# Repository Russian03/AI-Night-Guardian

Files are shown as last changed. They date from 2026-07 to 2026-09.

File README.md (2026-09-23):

# AI Night Guardian

> Acoustic detection of night-time incidents in care homes, running locally
> on-device and **without recording or storing any audio**.

Submitted to **HackEstiu 2026** (Universitat Politècnica de Catalunya).

- **Team:** Jan Díaz Carreras-Candi · Guillem Guilera Aulet · Joan Montobbio Palmer
- **Affiliation:** ETSETB — Universitat Politècnica de Catalunya (UPC), Barcelona
- **Hardware:** Arduino UNO Q + Modulino (temperature / light) + USB-C lavalier microphone + 3D printed enclosure
- **License:** MIT — see [`LICENSE`](LICENSE)
- **Arduino Project Hub (public):** see [`Arduino Project Hub`](https://projecthub.arduino.cc/guillemguilera/ai-night-guardian-5e5ab9)
- **Edge Impulse™ project (public):** see [`Edge Impulse`](https://studio.edgeimpulse.com/public/1106722/live)
- **Demo video:** see [`Video`](https://youtu.be/zw-_enrB-u0)

---

## 1. The problem

In care homes, night staff work by rounds: they walk into each room to
check that the resident is all right. Depending on the facility, a given
room gets a visit roughly once an hour.

That means there is up to an hour in which nobody knows what is happening
inside a room. If someone falls, if someone is in distress, it gets noticed
on the next round — not when it happens.

The obvious technical fix is a camera or an always-on microphone. But these
are people's bedrooms, and continuous recording in a resident's room is not
something anyone should accept. Any system that goes in there has to work
without keeping the audio.

## 2. The solution

**AI Night Guardian** is a device built on an Arduino UNO Q that runs a
neural network **locally** to classify sounds inside a room. It doesn't
replace the rounds — it covers the time between them.

The model distinguishes five kinds of sound, chosen so that each one maps
to a different action:

| Class | What it covers | Device action |
|---|---|---|
| `impacte` | Impacts, falls, doors | Alert |
| `veu_angoixa` | Screaming, crying, distress | Alert |
| `tos` | Coughing fits | Alert |
| `normal` | Speech, snoring, rain, traffic, alarms | Nothing |
| `silenci` | A quiet room | Nothing |

When it detects an incident, the device records the time and the type and
publishes a notification to the staff's mobile app, so carers can
prioritise the rooms that actually need attention.

**Additional:**

In the app you can find the temperature and light information of each room via the two Modulino sensors.

Because it is a **low-cost system with local processing**, it can be
deployed in care homes, assisted-living facilities and even in the homes of
older people living alone.

## License

MIT — see [`LICENSE`](LICENSE).

The source datasets (AudioSet, FSD50K, COUGHVID, ESC-50) keep their own
licenses; check them before redistributing `dataset_final_16khz/`.

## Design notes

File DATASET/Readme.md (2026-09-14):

Datasets:
* AudioSet: millions of 10s clips extracted from YouTube; it does not have video files, only a .csv file with the videos' IDs and the start and end time of each clip, as well as the assigned classes.
  - URL: https://research.google.com/audioset/download.html
* Coughvid: more than 20000 recordings of coughing sounds.
  - URL: https://zenodo.org/records/4048312
* ESC 50: 2000 5s audios, with special focus on environmental sounds.
  - URL: https://github.com/karolpiczak/esc-50
* FSD50K: more than 50000 audio clips from Freesound with 200 different sound-classes. The audios' length varies between 0.3s and 30s.
  - URL: https://zenodo.org/records/4060432

Scripts:
* audioset_extractor.py: filters the dataset and donwloads only the selected videos.
* coughvid_extractor.py: filters the locally downloaded coughvid dataset.
* esc50_extractor.py: filters the locally downloaded esc50 dataset.
* fsd50k_extractor.py: filters the locally downloaded coughvid dataset.
* UNIFICADOR.py: converts all selected videos by the previous scripts to 16kHz mono format.

Requisites:
* python3
  - os
  - pandas
  - sutil
  - subprocess
* FFmpeg

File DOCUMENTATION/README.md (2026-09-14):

# AI Night Guardian — Reproduction Guide

Complete guide to build the system from scratch: 3D-printed parts, Arduino UNO Q firmware and mobile app.

No prior knowledge of Arduino, Flutter or 3D printing is assumed. Follow the blocks in order: block 3 (firmware) only depends on block 2 if you want the enclosure assembled, but block 4 (app) requires the firmware to be running first.

---

## 0. Repository layout

```
APP/                        Mobile application (Flutter)
ARDUINO/
  ├── ai_night_guardian_firmware.tar.gz        Full Arduino App Lab application
  └── 3D_DESIGNS/                              Enclosure models (.obj / .stl)
```

Inside the `.tar.gz`, the App Lab application has this shape:

```
ai_night_guardian_firmware/
  ├── app.yaml              App Lab application definition
  ├── python/
  │    ├── main.py          Entry point: launches the three processes
  │    └── device_identity.py   Identity + QR generator
  ├── ai_night_guardian/
  │    ├── bleperipheral.py     BLE provisioning
  │    ├── mqtt_publisher.py    Heartbeat, sensors and configuration
  │    ├── audio_publisher.py   Audio inference and event publishing
  │    └── *.eim                Edge Impulse model
  ├── sketch/sketch.ino     Microcontroller code (Modulino sensors)
  └── requirements.txt      Python dependencies
```

---

## 1. What you need

**Hardware**

| Item | Notes |
|---|---|
| Arduino UNO Q (4 GB) + USB-C power	| The MPU side is what runs Linux and the model | 
| USB-C microphone	| Audio input for the classifier | 
| USB-C hub	| The board has a single USB-C port, so the hub is what lets you power it and plug the microphone in at the same time | 
| Modulino temperature and light sensors	| Daisy-chained over Qwiic/I2C | 
| USB-C cable to PC	| For the initial setup | 
| Android phone	| For the app | 

**Software on the PC**

| Program | Purpose |
|---|---|
| [Arduino App Lab](https://www.arduino.cc/en/software) | Load and run the firmware |
| [Ultimaker Cura](https://ultimaker.com/software/ultimaker-cura/) | Prepare the 3D parts |
| [Flutter SDK](https://docs.flutter.dev/get-started/install) | Build the app |
| [Git](https://git-scm.com/) | **Required**: the Flutter SDK uses it internally, and without it no `flutter` or `dart` command works |
| Android Studio (or just the command-line tools + SDK) | Build for Android |

---

## 2. 3D-printed parts

The files live in `ARDUINO/3D_DESIGNS/`. An `.stl` or `.obj` is geometry only: it describes the shape but knows nothing about your printer. You need a **slicer** to turn that shape into the movement instructions the machine understands (a `.gcode` file).

### 2.1 Preparing the file in Cura

1. Install Ultimaker Cura and open it.
2. On first launch it asks you to **add a printer**. Pick your exact model from the list. If it isn't there, use *Add a non-networked printer → Custom* and enter the build volume and nozzle diameter (usually 0.4 mm). This step is what makes the resulting `.gcode` valid for your machine.
3. `File → Open File(s)` and select the `.stl` (or the `.obj`; Cura accepts both, `.stl` being the standard for printing).
4. The part appears on the virtual bed. Check:
   - **Orientation**: use *Rotate* to lay the largest flat face on the bed. It reduces supports and improves adhesion.
   - **Size**: with *Scale*, verify the dimensions are what you expect. If the model imports 1000× too small, that's a unit problem in the `.obj` — use the `.stl` instead.

### 2.2 Recommended settings

| Setting | Value | Reason |
|---|---|---|
| Material | PLA | Enough for indoor use, easiest to print |
| Layer height | 0.2 mm | Balance between quality and time |
| Infill | 15–20 % | The enclosure carries no load |
| Walls | 2–3 | Sufficient rigidity |
| Supports | Only for overhangs >45° | Cura highlights them in red once *Support* is enabled |
| Bed adhesion | *Brim* | Stops corners from lifting |

### 2.3 Printing

1. Click **Slice** (bottom right). Cura computes the toolpath and shows estimated time and material.
2. Check the *Preview* view to make sure no layers are printing into thin air.
3. **Save to Disk** or **Save to Removable Drive**: writes the `.gcode` to the printer's SD card or USB stick.
4. Insert the media into the printer, pick the file on its screen and start the print.

Print every part in the directory before assembling. The microphone must line up with the grille in the enclosure: do not cover it with material, inference depends directly on the acoustic signal.

---

## 3. Arduino UNO Q firmware

### 3.1 First contact with the board

1. Install **Arduino App Lab** on the PC and open it.
2. Connect the UNO Q to the PC with the USB-C cable and wait for App Lab to detect it.
3. Enter the **board's WiFi credentials** when prompted. This is the network the device publishes from over MQTT; it must be the same network (or one with Internet access) that the phone uses.
4. If App Lab offers a board system update, install it and reboot. Do this now, not after loading the application.

### 3.2 Loading the application

App Lab imports packaged applications. Extract the tar first if your version only accepts a folder or a `.zip`:

```bash
tar -xzf ai_night_guardian_firmware.tar.gz
```

In the interface:

1. Go to **My Apps**.
2. Click **Create New App → Import App**.
3. Select the **whole** package (the `.tar.gz` or the complete `ai_night_guardian_firmware` folder, not individual files). The app bundles the Python code, the microcontroller sketch and `app.yaml`; if you import loose pieces, App Lab won't recognise it as an application.
4. The application shows up as a card under **My Apps**.

Terminal equivalent (from inside the UNO Q):

```bash
arduino-app-cli app import ai_night_guardian_firmware.tar.gz
```

### 3.3 Placing the AI model

The `.eim` file is the compiled model and may not be in the repository because of its size. If it's missing:

1. In Edge Impulse Studio, open the project → **Deployment**.
2. Choose **Linux (AARCH64)** and hit *Build*. You get an `.eim` file.
3. Copy it into the application's `ai_night_guardian/` folder over SCP:

   ```bash
   scp model.eim arduino@<UNO_Q_IP>:/home/arduino/ArduinoApps/ai_night_guardian_firmware/ai_night_guardian/
   ```

4. Make it executable (it's a binary, not a data file):

   ```bash
   ssh arduino@<UNO_Q_IP> "chmod +x /home/arduino/ArduinoApps/ai_night_guardian_firmware/ai_night_guardian/*.eim"
   ```

5. Open `audio_publisher.py` and check that the `EIM_PATH` constant holds **exactly** your file name. If it doesn't match, the script falls into its retry loop and never classifies anything.

### 3.4 Setting the microphone

`audio_publisher.py` has `AUDIO_DEVICE_ID = 8`. That number identifies the microphone on *that* board and changes with the hardware and the order things were plugged in. To find yours, in the UNO Q terminal:

```bash
python3 -m sounddevice
```

Find your microphone in the list (or the `default` entry) and put its index in `AUDIO_DEVICE_ID`.

### 3.5 Running it

1. With the application open in App Lab, press **Run**. The first run installs the dependencies from `requirements.txt` and takes several minutes.
2. Open the App Lab **Console**. You should see, in this order:

   ```
   [AI Night Guardian] device_id: AING-XXXXXX
   BLE peripheral launched
   MQTT publisher launched
   Audio publisher launched (nice 10)
   [MQTT audio] Conectado al broker, codigo: Success
   [AI Night Guardian] Modelo cargado. Clases: [...]
   [ESCUCHA] Micrófono e inferencia ACTIVOS
   ```

   If it keeps repeating *Audio no disponible todavía*, go back to 3.3 and 3.4.
3. This first run creates `device_identity.json` and `provisioning_qr.png` inside the application folder. **Download that PNG** — it's the QR the app scans to pair:

   ```bash
   scp arduino@<UNO_Q_IP>:/home/arduino/ArduinoApps/ai_night_guardian_firmware/python/provisioning_qr.png .
   ```

   Print it and stick it on the enclosure. Never publish it anywhere: it contains the device's pairing key.

### 3.6 Run at startup

A monitoring device has to come back on its own after a power cut, without anyone opening App Lab.

1. In the top right corner, next to the **Run** button, click the **arrow (▼)** to open the menu.
2. Turn on the **Run at startup** toggle.
3. A **DEFAULT** badge appears next to the application name, confirming it will start on boot.

Terminal equivalent:

```bash
arduino-app-cli properties set default user:ai_night_guardian_firmware
```

Test it for real: unplug power, plug it back in, wait a minute and check that the device reappears in the app.

---

## 4. Mobile application

The code is in `APP/`. It's built with Flutter and validated on Android.

### 4.1 Setting up the environment

1. Install **Git** and confirm it responds from a fresh terminal:

   ```bash
   git --version
   ```

   Without it, Flutter commands fail with errors about `update_engine_version`.
2. Install the **Flutter SDK** and add it to your PATH.
3. Run the diagnostic and fix everything it flags in red:

   ```bash
   flutter doctor
   ```

   For Android you need the SDK installed and the licences accepted (`flutter doctor --android-licenses`).

### 4.2 Build and install

```bash
cd APP
flutter pub get
```

With the phone connected over USB and **USB debugging** enabled in developer options:

```bash
flutter devices     # confirm your phone shows up
flutter run
```

To produce an APK you can install without a cable:

```bash
flutter build apk --release
```

The file lands in `build/app/outputs/flutter-apk/app-release.apk`. Copy it to the phone and install it, accepting the unknown-sources warning.

### 4.3 Phone permissions

Grant these when the app asks, or under *Settings → Apps → AI Night Guardian → Permissions*:

- **Camera**: scanning the device QR.
- **Bluetooth / Nearby devices**: BLE provisioning.
- **Location**: Android requires it for BLE scanning even though position is never used.
- **Notifications**: without this you won't see alerts.

The phone and the UNO Q must be on the **same WiFi network**.

---

## 5. Pairing device and app

With the firmware running (block 3) and the app installed (block 4):

1. Open the app → **Add device**.
2. **Scan the QR** stuck on the enclosure. The app reads the `device_id` and the pairing key.
3. The app looks for the device over **Bluetooth**. Keep the phone within a metre.
4. Enter the facility's **WiFi SSID and password** and confirm the **room name**.
5. Wait for confirmation. The process has a countdown of up to 90 seconds: it needs both the BLE reply **and** the first MQTT heartbeat. Don't leave the screen early.
6. The device appears in the list with a green indicator.

### Final check

1. Open the device detail view and confirm temperature and light are updating (they should refresh every few seconds).
2. Make sure the **acoustic listening** toggle is on. If it's off, the microphone is never even opened and nothing will be detected.
3. Trigger an event: clap loudly near the microphone. The UNO Q console shows the classification and, if it clears the threshold, `[EVENTO enviado]`; the notification should reach the phone within seconds.

Coughing won't fire on a single burst: the system requires several distinct coughs within a time window to tell a real coughing fit from throat-clearing. To test it, cough repeatedly for about half a minute.

---

## 6. Troubleshooting

| Symptom | Most likely cause | Fix |
|---|---|---|
| `Audio no disponible todavia` looping | `.eim` missing, not executable, or wrong `AUDIO_DEVICE_ID` | Review 3.3 and 3.4 |
| Many alerts from an empty room | Silence threshold (`SILENCE_RMS`) below the real background noise | Set `DEBUG_RMS = True` for a minute, read the idle values and raise the threshold |
| Temperature and light arrive as `null` | Inference is hogging the CPU | Confirm `main.py` launches the audio process with `nice -n 10` |
| Device shows as offline | The UNO Q lost WiFi or the process stopped | Check the App Lab console; confirm **Run at startup** is enabled |
| App can't find the device over BLE | Bluetooth or location permission off; provisioning window closed | Enable both and reboot the device to reopen the BLE window |
| No `flutter` or `dart` command works | Git isn't on the PATH | Install Git and open a new terminal |
| Icon or text doesn't update after rebuilding | Android cache | Uninstall the app from the phone, reboot it, then reinstall |

---

## 7. Privacy note

Audio is never stored or transmitted: it's processed in memory in one-second windows and discarded immediately after inference. The only thing leaving the device is text metadata (room, time, incident type). Any firmware change must preserve this property — it's the basis for the system qualifying legally as an automated emergency sensor rather than a listening microphone.

The default MQTT broker is public (`broker.hivemq.com`), which is fine for a demo. Before any real deployment it must be replaced by your own broker with TLS and per-device credentials.

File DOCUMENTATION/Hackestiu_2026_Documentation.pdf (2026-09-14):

## AI Night Guardian

Acoustic detection of night-time incidents in care homes, with on-device inference and no audio retention

Jan Díaz Carreras-Candi | Guillem Guilera Aulet | Joan Montobbio Palmer

FIB — Universitat Politècnica de Catalunya
| HackEstiu 2026

Abstract

In care homes, night staff check each room on rounds roughly once an hour, which leaves up to an hour in which nobody knows what is happening inside a room. AI Night Guardian is a low-cost device that listens to a room and alerts staff the moment it detects an incident, running a neural network locally on an Arduino UNO Q and without ever storing or transmitting audio. This document describes the system, the dataset pipeline, the model, the on-device decision logic and the mobile application, along with the measured results and the known limitations.

### Contents

1 Problem | 3
2 System overview | 3
3 Hardware | 4
4 Repository layout | 5
5 Dataset | 6
6 Model | 7
7 On-device runtime | 10

8 Mobile application | 12
9 Reproducing the system | 13
10 Limitations | 14
11 Future work | 15
Resources | 15

### 1 Problem

In care homes, night staff work by rounds: they walk into each room to check that the resident is all right. Depending on the facility, a given room gets a visit roughly once an hour.
That means there is up to an hour in which nobody knows what is happening inside a room. If someone falls, if someone is in distress, it is noticed on the next round — not when it happens. The obvious technical fix is a camera or an always-on microphone. But these are people’s bedrooms, and continuous recording in a resident’s room is not acceptable, both as a matter of dignity and under GDPR. Any system deployed there has to work without keeping the audio.

Goal. A device that detects incidents at the moment they occur, costs little enough to be deployed in every room, and processes everything locally so that no audio ever leaves the room.

### 2 System overview

The device classifies the sound of the room into five categories, three of which raise an alert. When one fires, it publishes a short JSON message over MQTT and the staff’s mobile app raises a notification.

Class | Covers | Action
impacte | Impacts, falls, doors | Alert
veu_angoixa | Screaming, crying, distress | Alert
tos | Coughing fits | Alert
normal | Speech, snoring, rain, traffic, alarms None
silenci | A quiet room | None

Table 1: Classes and the action each one triggers on the device. The class names are the labels of the deployed impulse; the preprocessing scripts use the English equivalents (impact, distressed_voice, cough, normal).

Two non-acoustic alerts complete the system: temperature outside a configurable range, which matters during heatwaves, and changes in ambient light, which can flag a resident getting up in the middle of the night.

### 2.1 Architecture

ROOM
USB-C microphone --> Arduino UNO Q |
|-- MCU (Zephyr) sketch.ino
| Modulino Thermo + Light
| exposes read_sensors() over RouterBridge
‘-- Linux (Cortex-A) python/main.py audio_publisher.py mic -> .eim model -> events mqtt_publisher.py sensors + heartbeat + config ble_peripheral.py WiFi provisioning
| | | MQTT / TCP 1883

| residencia/<device_id>/{heartbeat,eventos,config}
| v
Mobile app (Flutter)
QR + BLE onboarding, dashboard, notifications

The split matters: the microcontroller only reads the two I²C sensors and answers requests over RouterBridge, while everything acoustic happens on the Linux side, where the Edge Impulse™ runtime and the MQTT client live. Audio never reaches the MCU.

Incident flow. Microphone → 1 s window in RAM → Mel-filterbank energies → audio window discarded → inference → if the energy gate, the confidence threshold, the burst rule and the refractory period all pass, a JSON text message is published over MQTT.

### 2.2 Privacy by design

This is the core constraint of the project and the reason it is deployable in a care home.
- No personal or biometric data is processed or stored.
- The acoustic signal is captured straight into memory.
- Once inference has run, the audio window is immediately and irreversibly discarded, having never been written anywhere.
- No audio is transmitted outside the room.
- The only thing that leaves the device is text metadata. The app’s local incident history stores the same metadata and nothing else.

{"type": "event", "device_id": "AING-9D67B1",
"ts": "2026-09-12T02:40:11+0200",
"payload": {"room": "Room 14", "event_type": "impacte",
"confidence": 0.85}}

Legally, the system behaves as an automated emergency sensor rather than a listening microphone. The app additionally exposes a per-room listening switch; turning it off does not merely discard results, it shuts down the model process and releases the audio device (Section 7.2).

### 3 Hardware

Component | Role
Arduino UNO Q (4 GB) | Main board; Linux (Cortex-A) plus a Zephyr MCU
T’nB Influence Lapel Mic USB-C Audio capture, 16 kHz mono
USB-C hub | Connects microphone and power to the board
Modulino Thermo | Room temperature and humidity
Modulino Light | Ambient light level
3D printed enclosure | Four parts; STL and OBJ in the repository

Table 2: Bill of materials.

The two Modulinos are daisy-chained on the board’s Qwiic I²C connector and read from the MCU through the Arduino_Modulino library; no extra wiring is needed beyond the chain. The microphone is a plain USB audio device: it is enumerated by Linux, not by the MCU, and the inference process opens it by index (AUDIO_DEVICE_ID).

Enclosure. Four printed parts, in ARDUINO/3D_DESIGNS/ as both STL and OBJ: case_front, case_back, microphone_support and modulinos_support. The two supports hold the microphone and the sensor chain in place so that the acoustic port and the light sensor are not obstructed by the cabling.

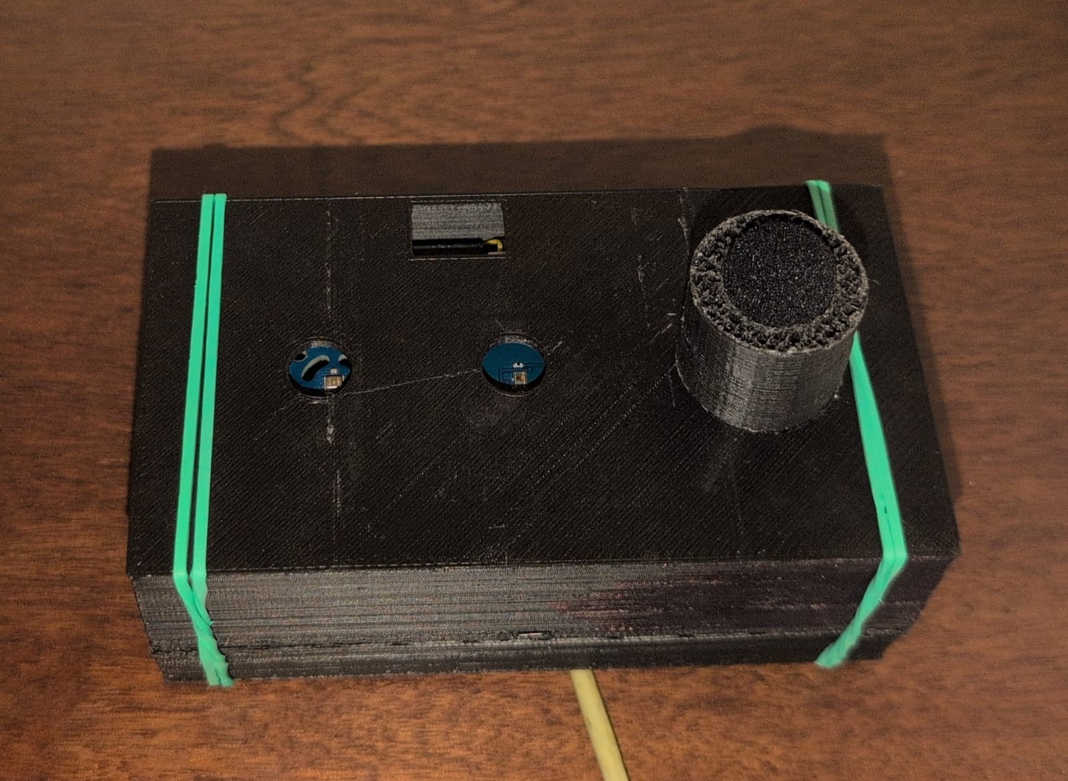
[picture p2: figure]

Figure 1: Device assembled.

### 4 Repository layout

Everything needed to rebuild the system is in the repository, including the audio collection and the deployed model binary.

AI-Night-Guardian/
|-- APP/ Flutter application (Android / iOS / desktop)
| |-- lib/data/ MQTT service, notifications, event log, storage
| |-- lib/presentation/ Screens: splash, home, devices, detail, QR,
| | BLE scan, WiFi provisioning, dashboard, settings
| ‘-- assets/translations/ ca.json, es.json, en.json
|-- ARDUINO/
| |-- 3D_DESIGNS/ Enclosure: 4 parts, STL + OBJ
| ‘-- ai_night_guardian_firmware.tar.gz
| sketch/sketch.ino MCU: Modulino + RouterBridge
| python/main.py Launches the three Linux processes | ai_night_guardian/
% audio_publisher.py Inference loop and decision logic % mqtt_publisher.py Sensor thread, heartbeat, config
% ble_peripheral.py GATT WiFi provisioning
% device_identity.py device_id, provisioning key, QR
% event_simulator.py Publishes fake incidents for demos
% *.eim Deployed Edge Impulse model (14 MB)
|-- DATA PREPROCESSING/ Dataset cleaning and preparation (6 scripts) | ‘-- recordings/ 501 two-second clips of the target room
|-- DATASET/
| |-- creation/Scripts/ Extractors for the four source datasets | ‘-- final_dataset_16khz/ 30,487 WAV clips, 16 kHz mono

|-- DOCUMENTATION/ This document and the design notes
‘-- LICENSE MIT

(The lines marked with % above are the contents of the firmware archive, which is shipped compressed.)

### 5 Dataset

The training set is built from public audio: 30 487 clips normalised to 16 kHz mono, in DATASET/final_dataset_16khz/.

Source | Clips | Origin
AudioSet (Google) | 10 463 10 s segments from YouTube
FSD50K (UPF) | 13 642 Zenodo
COUGHVID | 5 902 Zenodo — verified coughing
ESC-50 | 480 GitHub
Total | 30 487

Table 3: Source datasets. One extractor script per source, in DATASET/creation/Scripts/.

Each source needs a different extraction strategy. AudioSet ships no audio at all: the CSVs list YouTube IDs and time offsets, so clips are fetched with yt-dlp and cut with FFmpeg, and some are permanently unavailable. FSD50K requires crossing numeric file names against its ground-truth CSV. ESC-50 is filtered on the numeric target column of esc50.csv. COUGHVID is filtered on its own quality metadata, keeping only clips with cough_detected ≥ 0.95. A final UNIFICADOR.py pass re-encodes everything to 16 kHz mono.

Why 16 kHz mono. 16 kHz is the TinyML standard: by Nyquist it captures up to 8 kHz, and human voice, snoring and impacts carry practically all of their acoustic information below 4 kHz. Higher rates would only add useless high frequencies and inflate memory use during spectrogram generation. Mono, because the model does not need to know which side a sound came from. Re-encoding is lossless in practice — the files are uncompressed PCM — and it rewrites the WAV headers, which removes the stray metadata that otherwise causes upload errors in Edge Impulse™.

### 5.1 Cleaning

The raw collection is not usable as-is. Automated inspection found:

Exact duplicates (MD5) 2 634
Corrupt files (0.0 s) | 2 621
Clips shorter than 1 s | 1 540

Table 4: Problems found in the raw collection. Almost 17% was unusable.

Duplicates matter beyond wasted space: with several sources downloaded separately, the same file appears under different names, and if it is not removed before the train/test split it leaks across it.

### 5.2 From 47 source labels to 5 classes

The source labels are the ontology tags of the original datasets — 47 of them across the four sources. build_manifest.py maps each one to a final class, and deliberately discards some:

Discarded label | Reason
laughter, laughing | Shares vocal mechanism and burst structure
| with distress; rare at night
sneeze, burping | Not incidents, and they blur the cough bound-
| ary
respiratorysounds | Parent category of cough, snoring and breath-
| ing in AudioSet: contaminates both sides of the cough/normal boundary
insidesmallroom | Room-tone tag, not an event
silence | Handled by the energy gate on the device, and
| later as its own recorded class

Table 5: Labels excluded from training and why.

Each class is then capped, with sampling stratified by original label so that a class is not filled by a single source (for instance normal consisting only of speech). Caps: 2 000 for impacte and veu_angoixa, 1 500 for tos, 2 500 for normal, 800 for anything else; the critical classes stay below their cap in practice. The residual imbalance is handled with auto-weighted classes during training. All sampling uses a fixed seed (42), so the manifest is reproducible.

### 5.3 Pipeline

The scripts in DATA PREPROCESSING/ turn the raw collection into a training set. They run in this order:
1. build_manifest.py — consolidates the source labels, detects duplicates by MD5, flags corrupt and short files, applies the caps, and writes one CSV row per file with a keep_for_training decision.
2. materialize_dataset.py — copies the selected clips into one folder per class.
3. segment_events.py — energy-based segmentation into 2 s samples: it finds every region more than 10 dB above the clip’s own noise floor, merges regions closer than 0.25 s, drops peaks shorter than 0.08 s and exports up to 3 per clip. Continuous classes (normal) get random windows instead, because looking for peaks there would manufacture transients that resemble impacts.
4. yamnet_clean.py — semantic segmentation, which supersedes the previous step for the final dataset (Section 6.2).
5. augment_gain.py — random gain per clip (Section 6.5).
6. prepare_room_audio.py — builds the silenci class from a recording of the target room, as 2 s windows with 1 s hop.

Planned versus implemented augmentation. The initial design notes proposed background-noise injection, pitch shifting, time stretching and SpecAugment in addition to gain. Only gain augmentation was implemented, because it was the transformation that addressed a failure actually observed on the device (Section 6.5); the others remain as future work, and Edge Impulse™ can apply noise and time-shift augmentation in the training block itself.

### 6 Model

### 6.1 Class design

The first version had ten classes and scored 46.1%. The problem was not acoustic difficulty but design: most of those classes existed only to say “this is not an incident”, and they competed over distinctions that change nothing about what the system does.
The final taxonomy has five classes, one per action. Three of the merges are worth explaining.

door belongs with impacte. A door slamming and a body hitting the floor produce the same low-frequency transient. Trying to separate them left the fall class at 9% accuracy; merging them took it to 74%. At night, inside a room, a door is also worth checking.

Screams and crying are merged. They confused each other (26.7%) and raise exactly the same alert, so separating them asked the model for a distinction that serves no purpose.

Snoring goes to normal, and is not discarded. It is the dominant sound all night in a care home. Without somewhere correct to put it, the model files it as coughing or distress and raises false alarms every night.
The granularity given up here is recovered on the device: the mapping from class to action is deterministic and lives in the code, not in the network.

### 6.2 Label quality

For several iterations the model sat around 50–53% and nothing moved it: neither more epochs, nor more capacity, nor a different architecture.
The clue was that training and validation accuracy were nearly identical. A model that cannot fit its own training data does not have a capacity problem; it has a data problem.
FSD50K and AudioSet use weak labels: the tag means the sound appears somewhere in a ten-second clip, not that it fills it. A clip labelled cough may hold one second of coughing and nine of something else. Energy-based segmentation does not fix this — it takes the loudest part of the clip, which is not necessarily the labelled sound.
To measure it, the collection was passed through YAMNet — a model pretrained on AudioSet that classifies 521 sound types every 0.48 s — keeping only 2 s fragments where it confirms the expected sound with confidence at least 0.10, at most three per clip. Clips where YAMNet confirms nothing are dropped entirely, which is precisely the case where the label was probably wrong.
Class | Clips discarded
veu_angoixa | 31%
impacte | 27%
normal | 8%
tos | 7%

Table 6: Fraction of clips where YAMNet confirmed nothing. The two critical classes had the dirtiest labels; tos, always the best performer, the cleanest.

With the filtered set, accuracy went from 64.4% to 75.5% while training on less data. A more aggressive filter (confidence 0.20 instead of 0.10) made things worse: it removed hard but legitimate examples, which are the ones needed to generalise. normal keeps only one fragment per clip rather than three, because it starts with far more clips and loses very few of them to the filter, which would otherwise leave it with nearly four times the samples of veu_angoixa.

### 6.3 Architecture

- Preprocessing: Mel-filterbank energies (MFE), 1 s window with 500 ms stride, 40 filters, 256-point FFT, noise floor −102 dB.

- Network: MobileNetV2 0.35, pretrained, Edge Impulse™ keyword-spotting transfer learning block, auto-weighted classes.
- Deployment: .eim binary for Linux aarch64, run by the Edge Impulse™ Python runtime on the UNO Q — 10 ms latency, 177 kB of RAM. The exact file shipped in the repository is granny-guardians-fr-linux-aarch64-v8-impulse-#1.eim.
Transfer learning was compared against a 1D CNN trained from scratch on identical data and configuration:
Class | Transfer learning | From scratch
impacte | 82.8% | 65.1%
veu_angoixa | 69.0% | 36.4%
tos | 81.6% | 85.5%
Overall | 75.0% | 68.3%

Table 7: Pretrained weights are worth about 8 points overall and more than 25 on the smallest class. Giving the from-scratch network more capacity (32/64 filters instead of 8/16) made it worse, not better: 67.1%.

### 6.4 The silence class

Once deployed, the device raised impacte alerts at 87–91% confidence in an empty room. Every step of the pipeline keeps only fragments with audible sound, so the model had never seen silence — and at night silence is most of the input. Handed something unlike anything in its training, the classifier had to spread the probability across the classes it knew. It had no option for “nothing is happening”.
Recording the target room with the deployment microphone and adding it as its own class fixed it: it learns at 97.9%, the most separable class in the set. The 501 two-second clips used are in DATA PREPROCESSING/recordings/. Silence is not passed through gain augmentation, since it is a class defined precisely by its level.

### 6.5 Signal level and gain augmentation

RMS (int16) dBFS

Training clip | 4 857 | −16.6
Clap near the microphone | 741 | −33
Clap across the room | 365 | −39
Fall off a sofa | 148 | −47
Normal conversation | 50–70 | −54
Quiet room | 24 | −62

Table 8: Measured signal levels. The deployed system works about 30 dB below the training data.

The MFE block is not level-invariant: it normalises against a fixed noise floor, so the same sound at two volumes produces different features. Reproducing the computation outside Edge Impulse™ with the project’s parameters confirmed it — features shift by 0.33 on a 0–1 scale, while the spectral shape is preserved almost exactly (correlation 0.96).
There is no single level to target either: the same event reads 148 or 741 depending on distance to the microphone. So rather than matching a level, the model is trained with a random gain per clip targeting between −50 and −15 dBFS, forcing it to rely on spectral shape instead of absolute volume. 15% of clips are left at their original level as a clean reference, gains are clamped to avoid clipping, and the output is written as 16-bit PCM on purpose: the real microphone is also 16-bit, so the loss of resolution at low levels is part of what the model has to cope with. This is also what makes the model robust to distance, which is the variable that changes most from room to room.

### 6.6 Results

Iteration | Change | Accuracy
1 | 10 classes, own CNN | 46.1%
2 | 8 classes | 53.3%
3 | 4 classes, transfer learning | 60.7%
4 | More data on critical classes | 64.4%
5 | YAMNet label cleaning | 75.5%
6 | silenci class | 76.8%
7 | Gain augmentation | 75.0%

Table 9: Validation accuracy across iterations.

Final model, validation set: silenci 97.9%, impacte 82.5%, tos 78.9%, veu_angoixa 69.0%, normal 62.4%. AUC-ROC 0.94; weighted precision, recall and F1 all 0.75. Per-class F1 follows the same order as the thresholds chosen on the device: tos 0.81, impacte 0.79, veu_angoixa 0.66.

On the test figure. Edge Impulse™’s Model testing applies a single 0.6 confidence threshold and files everything below it as uncertain, which accounts for 27–35% of windows. Those windows are mostly classified correctly; they simply do not clear the cut-off. The device uses per-class thresholds instead, so a single global threshold measures a configuration that exists nowhere. The threshold-independent figures — AUC-ROC 0.94 and F1 0.75 — are the meaningful ones.

A note on iteration 7. Gain augmentation lowers the score and improves the system. On the real device the previous version raised occasional impact alerts during ordinary conversation; this one does not. The validation set cannot see the difference, because the problem it solves — sensitivity to level and distance — only appears in deployment. Validation accuracy is not the product metric.

### 7 On-device runtime

Three processes run on the Linux side, started by python/main.py: the inference loop, the sensor and telemetry publisher, and the BLE provisioning peripheral.

Priorities. Inference is the dominant load and does not yield the CPU voluntarily, which was starving the read_sensors requests to the MCU — temperature and light arrived as null in the heartbeat. The audio process is therefore launched with nice -n 10 and the sensor reader runs in its own thread at a raised priority when permitted. The sensor thread spends nearly all its time blocked waiting for the MCU, so this costs the classifier no measurable real-time margin.

### 7.1 Decision logic

The impulse window is 1 s with a 500 ms stride, but the Linux runner feeds it continuously in chunks of about 64 ms, so roughly 16 overlapping classifications per second reach the decision logic — over an eight-hour night, hundreds of thousands per room. Even a tiny false-positive rate becomes an unusable number of notifications, and a system that cries wolf gets muted in the first week. Four filters sit between the model and the phone.

Energy gate. If the RMS of the window is below a calibrated floor, the classification is discarded before it is even looked at. The RMS is computed over the same ≈1 s the model sees, accumulated from the 64 ms chunks, because a single chunk can land in a pause or right on a click and give erratic values.

Per-class confidence thresholds. The model is less confident on distress than on impacts, so a single global threshold either misses screams or floods on impacts. In a safety system a false alarm costs less than a missed event, so the critical classes get lower thresholds.

Cough burst rule. A single cough, or clearing one’s throat, is not an incident; a persistent fit or a choking episode is. Coughs are counted within a sliding window and an alert is raised only once enough distinct coughs accumulate — consecutive overlapping windows of the same cough do not count twice.

Per-class refractory period. After an alert for a class, further alerts for that class are suppressed for a configurable window. One notification per coughing fit, not eighty. The timestamp is kept per class, not globally: with a single timestamp the sequence impact → cough → impact let the second impact through immediately.

Parameter | Meaning | Value
SILENCE_RMS | Energy gate, int16 RMS over 1 s | 80
CONFIDENCE_THRESHOLDS | veu_angoixa | 0.65
| impacte | 0.75
| tos | 0.65
DEFAULT_THRESHOLD | Any other class | 0.85
DEBOUNCE_SECONDS | Refractory period, per class | 60 s
COUGH_MIN_COUNT | Coughs needed to alert | 6
COUGH_WINDOW_SECONDS | Sliding window for the count | 60 s
COUGH_MIN_GAP_SECONDS | Minimum gap between two coughs | 0.8 s

Table 10: Decision parameters, at the top of audio_publisher.py.

The energy gate is derived from the room recording rather than guessed: the background measured 0.00074 RMS median (−62.6 dBFS, ≈24 in int16) and 0.00121 at the 95th percentile (−58.4 dBFS, ≈40), and the threshold is set at twice the 95th percentile.

rms = _rms(np.concatenate(audio_buffer))
if rms < SILENCE_RMS:
continue

top_label = max(scores, key=scores.get)
if top_label in IGNORED_LABELS: # normal, silenci
continue
if scores[top_label] < CONFIDENCE_THRESHOLDS.get(top_label, DEFAULT_THRESHOLD): continue

now = time.time()
if top_label == COUGH_LABEL and not _is_cough_fit(now): continue if now - last_event_ts.get(top_label, 0.0) < DEBOUNCE_SECONDS: continue
last_event_ts[top_label] = now
_publish_event(top_label, scores[top_label])

### 7.2 Listening switch

The switch in the app writes a flag that the device polls at most once a second. Turning it off raises an exception that unwinds the runner’s context manager, which terminates the model process and releases the audio device; the loop then idles until the flag comes back. Merely ignoring the results would save neither CPU nor temperature, and would leave the microphone open.
Two details are deliberate. Any read error on the flag file is treated as “keep listening”: in a safety system the fail-safe state is to keep watching. And the whole loop retries indefinitely, so the process can be started before the microphone is plugged in or the model copied, and picks up on its own once both exist.

### 7.3 Telemetry robustness

Bridge.call() is blocking with a 10 s timeout, so reading the sensors from the publishing loop would stall the heartbeat whenever the MCU hiccups. The reader therefore runs in its own thread and writes into a cache; the publisher only ever reads the cache. Readings older than 60 s are published as null rather than as a stale value — an honest gap is better than a wrong number — and consecutive failures are logged on the first and then every tenth, so a downed MCU does not flood the log. MQTT reconnection is retried on a 10 s backoff, and the heartbeat keeps its cadence throughout.

### 8 Mobile application

A Flutter application, built for Android (and buildable for iOS, Linux, macOS, Windows and web), in three languages: Catalan, Spanish and English.

Onboarding. Splash → Add device → scan the QR shown by the device, which carries its device_id and provisioning key → BLE scan → WiFi form, with the network list read from a scan and a room name → the device connects and publishes its first heartbeat → the room appears on the dashboard. Required permissions: Bluetooth, camera, location (needed for BLE scanning on Android) and notifications.

Running screens. A home screen with one live card per room; a device detail screen with temperature, light, uptime, signal, last incident and the listening switch, plus a technical dialog showing the MQTT topic, the age of the last heartbeat and of the last sensor reading, and the broker state; a device list with swipe actions to rename or unpair; and settings for language and notifications.

Two kinds of notification. Incidents are delivered at maximum importance. Loss of signal is delivered at normal importance and is a safety feature in its own right: a watchdog checks every 30 s and, if no heartbeat has arrived for 90 s — eighteen missed heartbeats — the room is marked offline and the staff are told, once, that the sensor stopped reporting. A device that has silently died must not look like a quiet room. Sensor values that stop updating are flagged as stale in the interface rather than shown as current.

Local history. Incidents are kept on the phone for 24 hours, at most 30 per device, as metadata only — room, type, confidence, timestamp. No audio exists to store.

### 8.1 Communication protocols

All MQTT messages are JSON with v, type, device_id, ts and payload.

Topic | Direction | Contents
residencia/<id>/heartbeat | device → app Liveness every 5 s
residencia/<id>/eventos | device → app Detected incident (QoS 1)
residencia/<id>/config | app → device Configuration (QoS 1)

Table 11: MQTT topics.

The heartbeat carries the room name, firmware version, uptime, signal strength, temperature, light level and the current state of the listening switch, so the app can show the room as online without any polling. The configuration topic currently carries one key, {"listening": true|false}.
WiFi provisioning uses a Nordic UART style BLE service (6e400001-b5a3-f393-e0a9-e50e24dcca9e): the app writes SSID, password and room name to the TX characteristic, and subscribes to a STATUS characteristic that reports connecting, connected with the assigned IP, or failed
with the reason. The device brings the network up with nmcli.

### 9 Reproducing the system

Everything is open source under the MIT licence. The audio collection, the preprocessing scripts and the deployed model binary are all in the repository, so any stage can be reproduced without rebuilding the previous one.

### 9.1 Rebuilding the dataset

pip install numpy soundfile
pip install tensorflow tensorflow-hub # only for yamnet_clean.py

cd "DATA PREPROCESSING"
python build_manifest.py ../DATASET/final_dataset_16khz manifest.csv python materialize_dataset.py manifest.csv dataset_ready
python yamnet_clean.py dataset_ready dataset_ready_yamnet
python augment_gain.py dataset_ready_yamnet dataset_ready_gain
python prepare_room_audio.py recording.wav dataset_ready_gain/silenci

The result is one folder per class of 2-second WAV clips at 16 kHz mono, ready to upload to Edge Impulse™. To re-extract the collection from the original sources instead, the four extractors and the unifier are in DATASET/creation/Scripts/. Alternatively, the Edge Impulse™ project is public and can be cloned directly.

### 9.2 Running the device

Requirements: Arduino CLI with the arduino:zephyr platform, Python 3.11+ on the board’s Linux side, nmcli (NetworkManager) and BlueZ.

tar xzf ARDUINO/ai_night_guardian_firmware.tar.gz
cd ai_night_guardian_firmware
pip install -r python/requirements.txt # qrcode, paho-mqtt, edge-impulse-linux

pip install numpy bluezero

# 1) Build and upload the sketch to the MCU (Modulino + RouterBridge) cd sketch

arduino-cli compile --profile default . \
&& arduino-cli upload -p <PORT> --profile default .

# 2) Generate the device identity and its provisioning QR cd ../ai_night_guardian

python3 device_identity.py

# 3) Everything at once: BLE + telemetry + inference cd ..

python3 python/main.py

The processes can also be run individually for debugging: ble_peripheral.py (needs root), mqtt_publisher.py and audio_publisher.py. event_simulator.py publishes a fake incident, which is the quickest way to test the app end to end without making noise. Set AUDIO_DEVICE_ID in audio_publisher.py to the index of the USB microphone as Linux enumerates it.

### 9.3 Calibrating for a new room

Gain augmentation is what allows the same model to work across rooms without retraining. For best results there is an optional calibration step: record roughly fifteen minutes of the target room with no incidents — mostly empty and quiet, with a few minutes of television and of ordinary background — and run prepare_room_audio.py. It reports the RMS levels, which set the energy gate, and produces clips that can be added as the silenci class for a room-specific retrain. The whole procedure takes minutes and requires no machine-learning knowledge, which is the point: the system works out of the box and calibrates like any other sensor.

### 10 Limitations

A fall and a closing door sound the same. This is a limitation of the signal, not of the model: the information needed to separate them is not in the audio. Hence the class name impacte and the wording “possible incident” rather than “fall detected”. Thunder has the same problem; the light sensor already on the board could help rule it out.

Plosives look like small impacts. The /p/, /t/ and /k/ sounds in speech are broadband bursts with a sharp attack, and are the main source of false alarms while someone is talking in the room.

Precision is the weak point. Roughly 30% of normal windows are classified as some alert class. The decision logic described above is what makes the system usable in spite of this.

No clip in the dataset comes from a real care home. The system is trained on generic public audio and validated in private rooms. A real deployment would need recordings from the actual environment, with the consent that implies.

The MQTT broker is public. The prototype uses broker.hivemq.com, which is fine for development and unacceptable for a real deployment: the topics are readable by anyone who knows the device id, and the configuration topic is writable. A production system needs a private broker with TLS and authentication.

Timestamps depend on the network. There is no real-time clock, so the board takes the time from the network; without connectivity, event times drift.

### 11 Future work

- Improved 3D enclosure: Develop a better-designed 3D-printed enclosure to improve thermal isolation of the Arduino, enhance microphone sound capture, and provide better cable management.
- Larger and more diverse dataset: Expand the training dataset by collecting data from different care-home environments to improve the model’s generalization and detection performance.
- Audio feature in the application: Consider integrating an audio component into the application so that users can review detected sounds and determine whether an alert is a false alarm. These user validations could also be used as additional data for further AI model training.
- Improved connectivity and security: Increase connection stability and deploy a private MQTT broker with TLS encryption and authentication to improve the reliability and security of communication between devices.
- Real-world care-home recordings: Collect audio recordings in real care-home environments, with appropriate consent and privacy safeguards, to reduce the domain gap between the training data and real-world deployment conditions.

### Resources

- Source code: https://github.com/Russian03/AI-Night-Guardian
- Edge Impulse™ project (public): https://studio.edgeimpulse.com/public/1106722/live (https://studio.edgeimpulse.com/public/1106722/live)
- Demo video: https://youtu.be/zw-_enrB-u0

The source datasets (AudioSet, FSD50K, COUGHVID, ESC-50) keep their own licences; check them before redistributing the audio collection.

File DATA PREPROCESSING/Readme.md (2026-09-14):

# Data preprocessing

Scripts that turn the raw audio collection in `DATASET/final_dataset_16khz/`
into the training set uploaded to Edge Impulse™.

The reasoning behind each step is in the technical report
(`DOCUMENTATION/`). This file only covers how to run them.

## Requirements

```bash
pip install numpy soundfile
pip install tensorflow tensorflow-hub   # only for yamnet_clean.py
```

## Running the pipeline

From this folder, in order:

```bash
# 1. Inventory: consolidate labels, drop duplicates and corrupt files,
#    cap each class. Writes one CSV row per file.
python build_manifest.py ../DATASET/final_dataset_16khz manifest.csv

# 2. Copy the selected clips into one folder per class
python materialize_dataset.py manifest.csv dataset_ready

# 3. Segment into 2 s clips, keeping only fragments where YAMNet
#    confirms the labelled sound
python yamnet_clean.py dataset_ready dataset_ready_yamnet

# 4. Random gain per clip, so the model doesn't depend on absolute level
python augment_gain.py dataset_ready_yamnet dataset_ready_gain

# 5. Silence class, from a recording of the room (see below)
python prepare_room_audio.py recording.wav dataset_ready_gain/silenci
```

The result is `dataset_ready_gain/`, one folder per class of 2-second WAV
clips at 16 kHz mono, ready to upload to Edge Impulse™.

All sampling uses a fixed seed, so the output is reproducible.

## The scripts

| Script | What it does |
|---|---|
| `build_manifest.py` | Maps the 47 source labels to the 5 final classes, finds duplicates by MD5, flags corrupt and short files, applies per-class caps with sampling stratified by source label |
| `materialize_dataset.py` | Copies the clips marked `keep_for_training` into one folder per class |
| `segment_events.py` | Energy-based segmentation into 2 s clips. Superseded by `yamnet_clean.py` for the final dataset, but works without TensorFlow |
| `yamnet_clean.py` | Semantic segmentation: keeps only fragments where YAMNet confirms the expected sound, drops clips where it confirms nothing |
| `augment_gain.py` | Rescales each clip to a random level between −50 and −15 dBFS |
| `prepare_room_audio.py` | Cuts a long recording into 2 s clips and reports its RMS levels |

## `recordings/`

501 two-second clips of a quiet room, recorded with the deployment
microphone. This is the `silenci` class.

It exists because every other step of the pipeline keeps only fragments with
audible sound, so the model never saw silence — and at night silence is most
of what the microphone hears. Without a class for it, the classifier spread
the probability across the classes it knew and raised `impacte` alerts at
87–91 % confidence in an empty room.

These clips are **not** passed through `augment_gain.py`: silence is defined
by its level, so rescaling it would defeat the purpose.

### Recording your own

The class is specific to a room and a microphone. To adapt the system to a
new environment, record ~15 minutes of the target room with no incidents —
mostly quiet, with some background and a few minutes of television — and run:

```bash
python prepare_room_audio.py recording.wav silenci
```

Besides cutting the clips, it prints the RMS levels of the recording, which
is what sets the energy gate (`SILENCE_RMS`) on the device.

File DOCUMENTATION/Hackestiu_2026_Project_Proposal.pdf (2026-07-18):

# AI Night Guardian

Jan Díaz Carreras-Candi | Guillem Guilera Aulet | Joan Montobbio Palmer

## 1 Quin és el repte?

En residències de persones de la tercera edat, durant el torn de nit, el personal ha de realitzar rondes periòdiques per totes les habitacions per comprovar que els residents estiguin bé. Aquestes visites són necessàries per detectar possibles incidències, com ara caigudes, episodis de tos persistent, crits d’auxili o plors. Tot i això, aquestes rondes poden interrompre el son dels residents i sobretot, no garanteixen que una incidència sigui detectada en el moment en el que ocorre.

El repte que proposem de cara a la democratització de la intel·ligència artificial és solucionar aquest problema

d’ineficiència fent un model accessible per a totes les residències o centres sociosanitaris, que pugui identificar les diferents incidències durant els torns de nit sense comprometre la privadesa dels residents i que en cas de detcecció d’incidència el personal rebi una notificació amb la informació del que ha succeït.

## 2 Solució proposada

AI Night Guardian és un dispositiu basat en Arduino Uno Q que utilitza un model d’intel·ligència artificial

executat localment per a classificar sons rellevants dins d’una habitació, sense gravar ni emmagatzemar converses. El sistema distingeix esdeveniments com roncs, tos, cops, caigudes (quan generen un patró acústic identificable), crits demanant ajuda, plors o períodes de silenci prolongat després d’un soroll inesperat.

Quan detecta un esdeveniment d’interès, enregistra l’hora i el tipus d’incidència, i envia una notificació a una aplicació mòbil del personal. D’aquesta manera, els cuidadors poden prioritzar les habitacions que realment requereixen atenció immediata, reduint el temps de resposta i evitant un sistema de rondes ineficient que no permet detectar les incidències en el moment en que aquestes es produeixen.

Com a mesura de privacitat, el dispositiu no emmagatzema àudio ni gravacions, ni els retransmet a l’exterior o entitats externes a la residència. Tot el processament es realitza en el propi dispositiu i únicament es registra el resultat de la classificació (per exemple: ”Habitació 12 – 03:17 – Cop detectat”).

Aquest enfocament permet aprofitar la intel·ligència artificial de forma respectuosa amb la privacitat, millorant

la seguretat dels residents i optimitzant el treball del personal sanitari i assistencial. A més, al tractar-se d’un sistema de baix cost amb processament local, pot implementar-se fàcilment en residències, centres sociosanitaris i fins i tot en domicilis de persones grans que viuen soles.

També es poden introduir variacions, com per exemple plors de nens petits.

D’altra banda, es genera un altre tipus d’alertes en detectar un canvi important en la il·luminació de l’ambient (encesa/apagada de llums).

Finalment, es pot afegir una funcionalitat extra independent que monitoritzi la temperatura i envii avisos si aquesta se surt d’un interval configurable com per exemple [20◦C, 30◦C]. Aquesta funcionalitat es especialment important durant episodis d’onades de calor com els que s’han viscut recentment.

## 3 Hardware Requerit

A continuació apareix un llistat de tot el hardware necessari per aquest projecte:

1

- Arduino Uno Q 4GB o més amb cable d’alimentació
- Sensors modulino:

– temperatura

– llum

- mòdul micròfon I2S (per exemple el INMP441): Per a tal d’obtenir els sons que es passaran a la IA per

detectar esdeveniments.

- mòdul RTC (per exemple el DS3231): Per a tal d’obtenir la hora de forma precisa, ens cal un módul

real-time-clock. En cas que no sigui possible, de forma alternativa, es pot accedir a un servidor NTP mitjançant conexió wifi.

## 4 Observacions

Durant l’estudi de viabilitat del projecte, hem analitzat la possibilitat d’implementar-lo en residències, on el Reglament General de Protecció de Dades (RGPD) hi restringeix l’ús de tecnologies intrusives. La solució proposada resol aquest conflicte d’arrel aplicant la Privacitat des del Disseny. La nostra tecnologia no realitza cap tractament ni emmagatzematge de dades personals o biomètriques. El senyal acústic de l’habitació es capta en format streaming directament a la memòria del microcontrolador. Un cop la xarxa neuronal executa la inferència local, la finestra d’àudio s’esborra immediata i irreversiblement sense haver estat mai enregistrada. Com que el dispositiu només genera i transmet metadades de text del tipus “Habitació 14 – 02:40 – Cop detectat”, el sistema actua legalment com un sensor d’emergències automatitzat i no com un micròfon d’escolta. Es molt important per a nosaltres mantenir ´

la privacitat dels residents i per això si accepteu el nostre projecte prometem no implementar cap sistema que pugui vulnerar la seva intimitat.

2

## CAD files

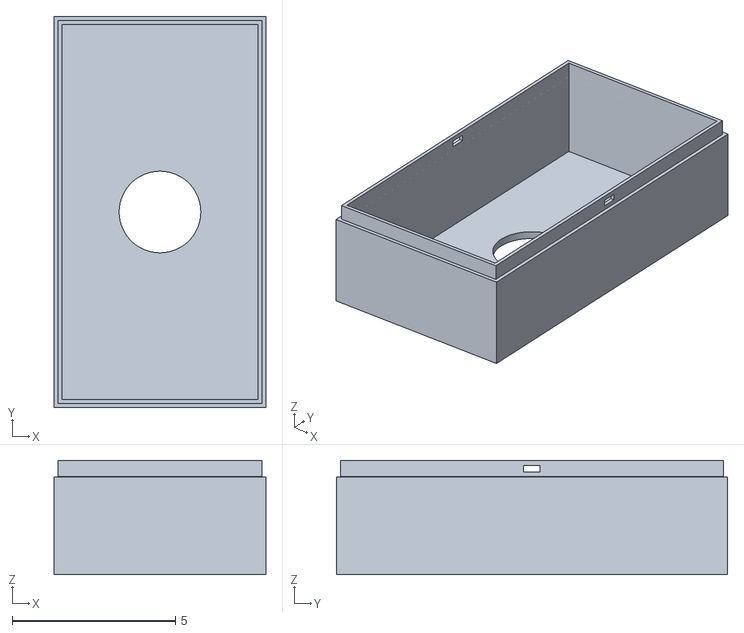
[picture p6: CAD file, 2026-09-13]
ARDUINO/3D_DESIGNS/case_back.stl
6.50 x 12.0 x 3.50

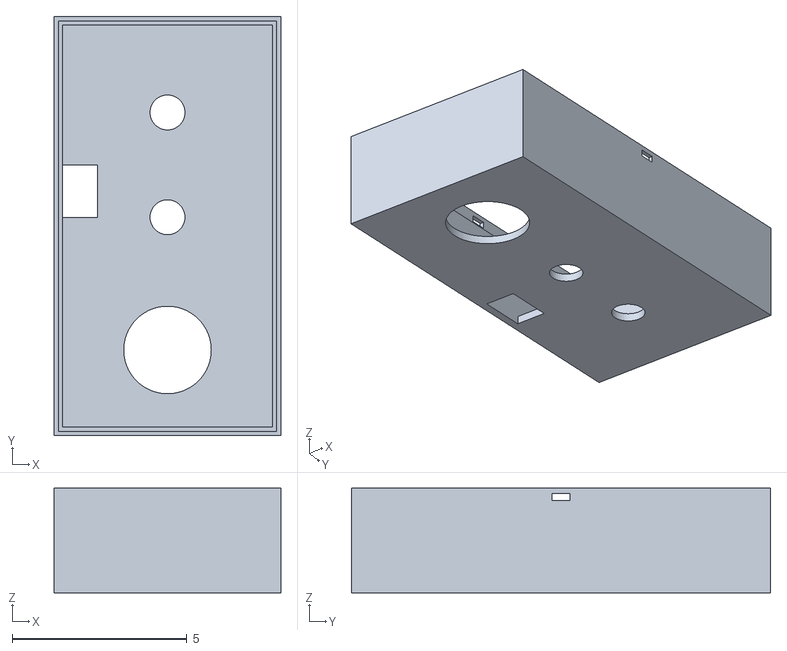
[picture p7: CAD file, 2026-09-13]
ARDUINO/3D_DESIGNS/case_front.stl
6.50 x 12.0 x 3.00

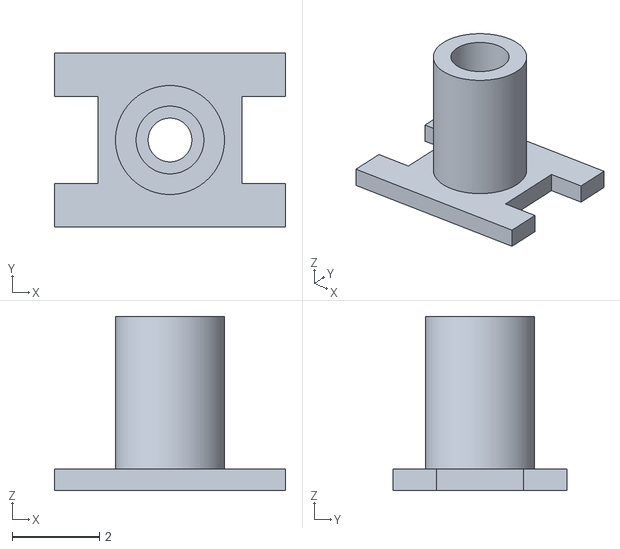
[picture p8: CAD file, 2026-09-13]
ARDUINO/3D_DESIGNS/microphone_support.stl
5.30 x 4.00 x 4.00

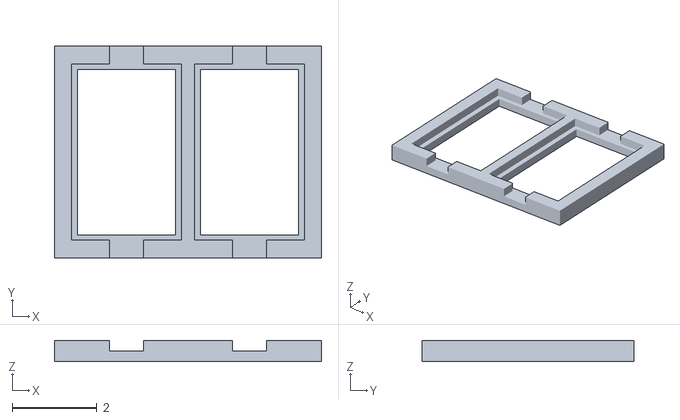
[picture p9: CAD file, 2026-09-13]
ARDUINO/3D_DESIGNS/modulinos_support.stl
6.30 x 5.00 x 0.5

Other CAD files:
ARDUINO/3D_DESIGNS/case back.obj
ARDUINO/3D_DESIGNS/case front.obj
ARDUINO/3D_DESIGNS/microphone support.obj
ARDUINO/3D_DESIGNS/modulinos support.obj

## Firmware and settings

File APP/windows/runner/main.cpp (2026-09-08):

#include <flutter/dart_project.h>
#include <flutter/flutter_view_controller.h>
#include <windows.h>

#include "flutter_window.h"
#include "utils.h"

int APIENTRY wWinMain(_In_ HINSTANCE instance, _In_opt_ HINSTANCE prev,
                      _In_ wchar_t *command_line, _In_ int show_command) {
  // Attach to console when present (e.g., 'flutter run') or create a
  // new console when running with a debugger.
  if (!::AttachConsole(ATTACH_PARENT_PROCESS) && ::IsDebuggerPresent()) {
    CreateAndAttachConsole();
  }

  // Initialize COM, so that it is available for use in the library and/or
  // plugins.
  ::CoInitializeEx(nullptr, COINIT_APARTMENTTHREADED);

  flutter::DartProject project(L"data");

  std::vector<std::string> command_line_arguments =
      GetCommandLineArguments();

  project.set_dart_entrypoint_arguments(std::move(command_line_arguments));

  FlutterWindow window(project);
  Win32Window::Point origin(10, 10);
  Win32Window::Size size(1280, 720);
  if (!window.Create(L"ai_guardians", origin, size)) {
    return EXIT_FAILURE;
  }
  window.SetQuitOnClose(true);

  ::MSG msg;
  while (::GetMessage(&msg, nullptr, 0, 0)) {
    ::TranslateMessage(&msg);
    ::DispatchMessage(&msg);
  }

  ::CoUninitialize();
  return EXIT_SUCCESS;
}

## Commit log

2026-09-10 arduino firmware must fix micro
2026-09-13 3D designs
    [case back.obj, case front.obj, microphone support.obj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]
2026-09-13 Ordering Project
    [case back.obj, case front.obj, microphone support.obj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]
2026-09-13 3d objects .stl
    [case_back.stl, case_front.stl, microphone_support.stl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]
2026-09-13 notis millora
2026-09-14 Translate comments and messages to English
    Updated comments and print statements to English for consistency.
2026-09-14 Translate comments and print statements to English
    Updated comments and print statements to English for better clarity and accessibility.
2026-09-14 Clarify additional alerts section in README
    Updated the section on additional alerts to clarify the information provided by the sensors.
2026-09-14 Remove Arduino Project Hub link placeholder
    Removed placeholder for Arduino Project Hub link.
2026-09-23 Add Arduino Project Hub link to README
